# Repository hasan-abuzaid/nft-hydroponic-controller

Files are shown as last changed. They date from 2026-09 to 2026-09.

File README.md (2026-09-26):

# NFT Hydroponic Controller — Open-Hardware PCB

**Status: v1.1 boards fabricated and assembled by JLCPCB. Bring-up and on-site testing in progress.**

A 4-layer, ESP32-S3 based controller board that turns a manual NFT (Nutrient Film Technique) hydroponic system into a self-regulating one. It reads pH, EC and water level from the main reservoir, switches up to six 12 V pumps (nutrient A, nutrient B, pH adjust, circulation, …) and integrates natively with **Home Assistant** through **ESPHome**.

The goal: replace the breadboards, loose jumper wires and relay modules that most DIY hydroponic builds end up with, with one board you can order pre-assembled from JLCPCB, screw your sensors and pumps into, and flash.

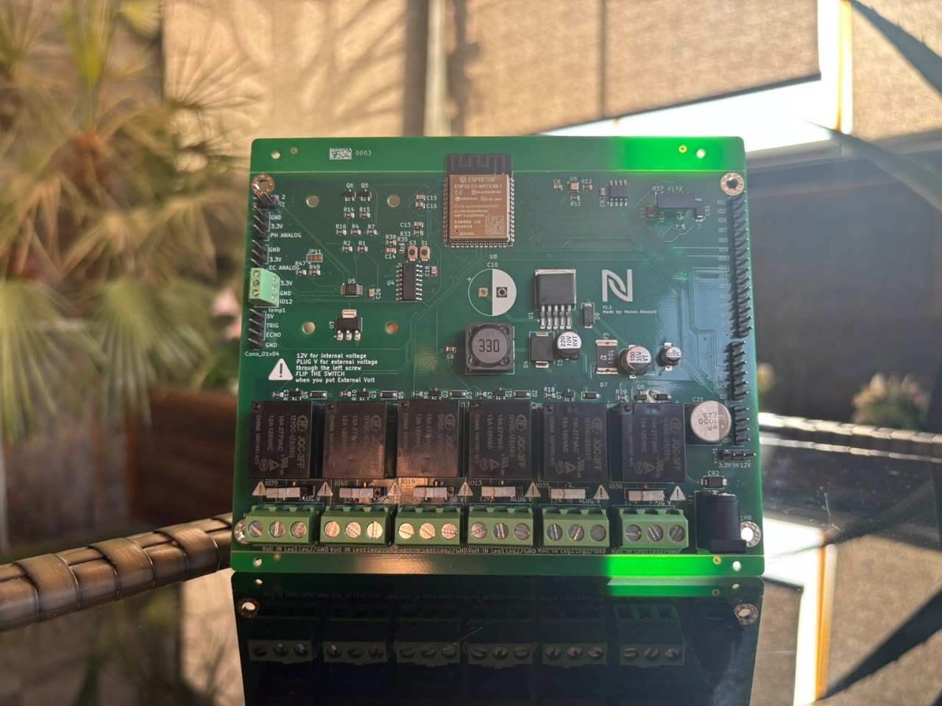
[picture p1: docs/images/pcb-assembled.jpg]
Assembled v1.1 board


---

## Why this exists

NFT systems work by running a thin film of nutrient solution under the plant roots. The hard part is not the plumbing, it is keeping the solution chemistry right: pH drifts, EC drops as plants feed, and the tank level falls. Doing that by hand every day is what makes most home systems fail.

This board closes that loop:

```
 pH / EC / level sensors ──► ESP32-S3 ──► Home Assistant (automations decide dose)
          ▲                                      │
          └──── main tank ◄── dosing pumps ◄── relays ◄─┘
```

The ESP reports readings, Home Assistant decides how much A/B nutrient or pH-down to dose based on calibrated set-points, and the board drives the pumps.

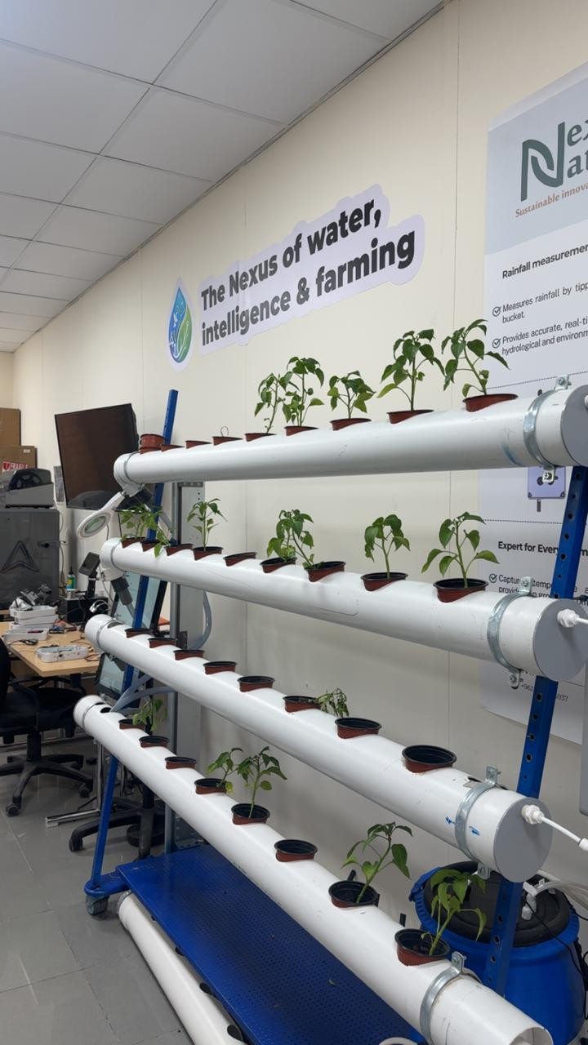
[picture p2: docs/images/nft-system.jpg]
The NFT system


---

## Features

| Block | Implementation |
|---|---|
| MCU | ESP32-S3-WROOM-1 (N16R8) — 16 MB flash, 8 MB PSRAM, Wi-Fi + BLE |
| USB | USB-C, CH340C USB-UART bridge with auto-reset/auto-boot (flash with no button presses), ESD protection on the data lines |
| Power input | 12 V DC barrel jack (DC-005, 2.0 mm) |
| Power conversion | LM2596S-5 buck (12 V → 5 V), AMS1117-3.3 LDO (5 V → 3.3 V) |
| Protection | SMAJ15A TVS on the 12 V rail, resettable polyfuse, Schottky OR-ing between USB and 12 V supply |
| Analog front-end | ADS1115 16-bit ADC for the pH and EC probe signals (far more stable than the ESP32's internal ADC) |
| Sensor inputs | pH and EC analog headers, water-temperature screw terminal, ultrasonic level header (5 V / TRIG / ECHO / GND), I²C header, GPIO breakout |
| Environment | On-board BME280 (air temperature, humidity, pressure) |
| Storage | MB85RC256V 32 KB I²C FRAM — stores calibration and state without flash wear |
| Outputs | 6× relay channels (JQC-3FF, SPDT) on 3-pin screw terminals (Volt IN / Leg 1 / Leg 2-GND), each with flyback diode and transistor driver |
| Load supply select | Per-channel switch: power the load from the board's internal 12 V, or from an external supply wired into that channel's Volt IN terminal |
| Buttons | BOOT and RESET |
| Power outputs | 3.3 V / 5 V / 12 V header for external modules |
| PCB | 4-layer, 1.6 mm, JLCPCB-ready (LCSC part numbers in the BOM) |

---

## Repository layout

```
.
├── nft-hydroponic-controller.kicad_pro   KiCad project (open this)
├── nft-hydroponic-controller.kicad_sch   Schematic
├── nft-hydroponic-controller.kicad_pcb   PCB layout
├── nft-hydroponic-controller.kicad_dru   Custom design rules
├── nft-hydroponic-controller.csv         Bill of materials with LCSC part numbers
├── nft-hydroponic-controller.xml         Netlist
├── DRC.rpt, ERC.rpt                      Design rule / electrical rule check reports
├── libs/lcsc/                Symbols, footprints and 3D models imported from LCSC
├── Custom_JLCPCB_Parts/      Custom parts library
├── compunents/               Additional vendor symbols/footprints
├── fp-lib-table, sym-lib-table   Project-relative library tables
├── firmware/esphome/         ESPHome config + secrets template
└── docs/images/              Photos and renders
```

All library paths are project-relative, so the project opens without missing symbols or footprints on a fresh machine.

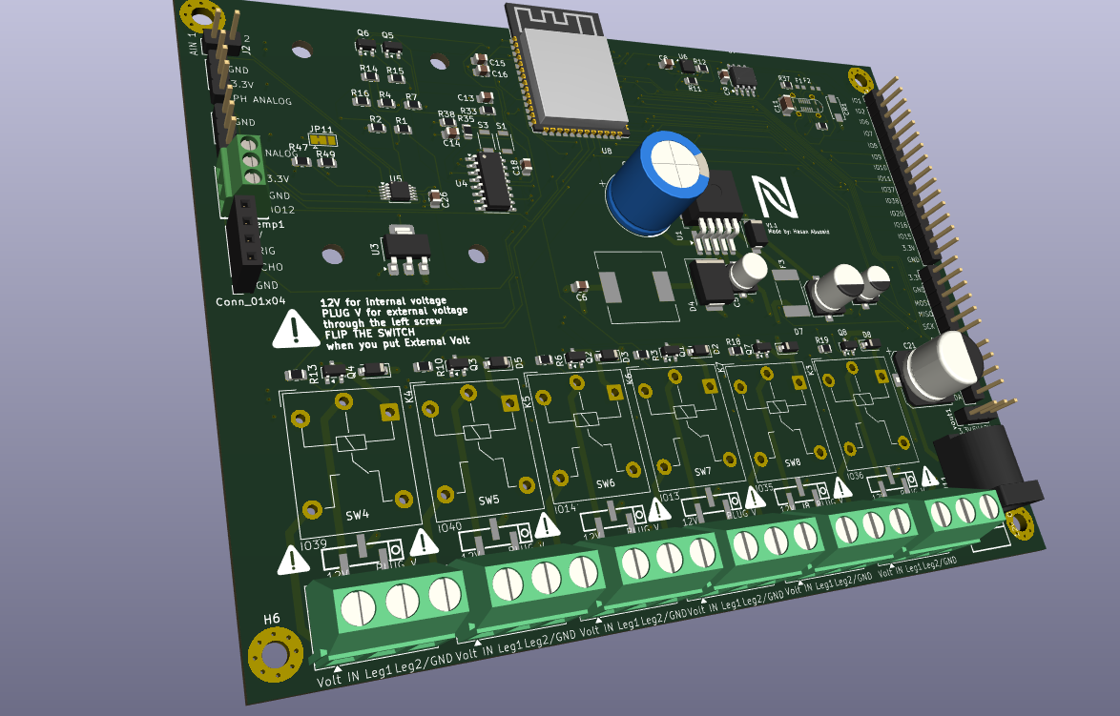
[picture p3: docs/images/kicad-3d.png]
3D render

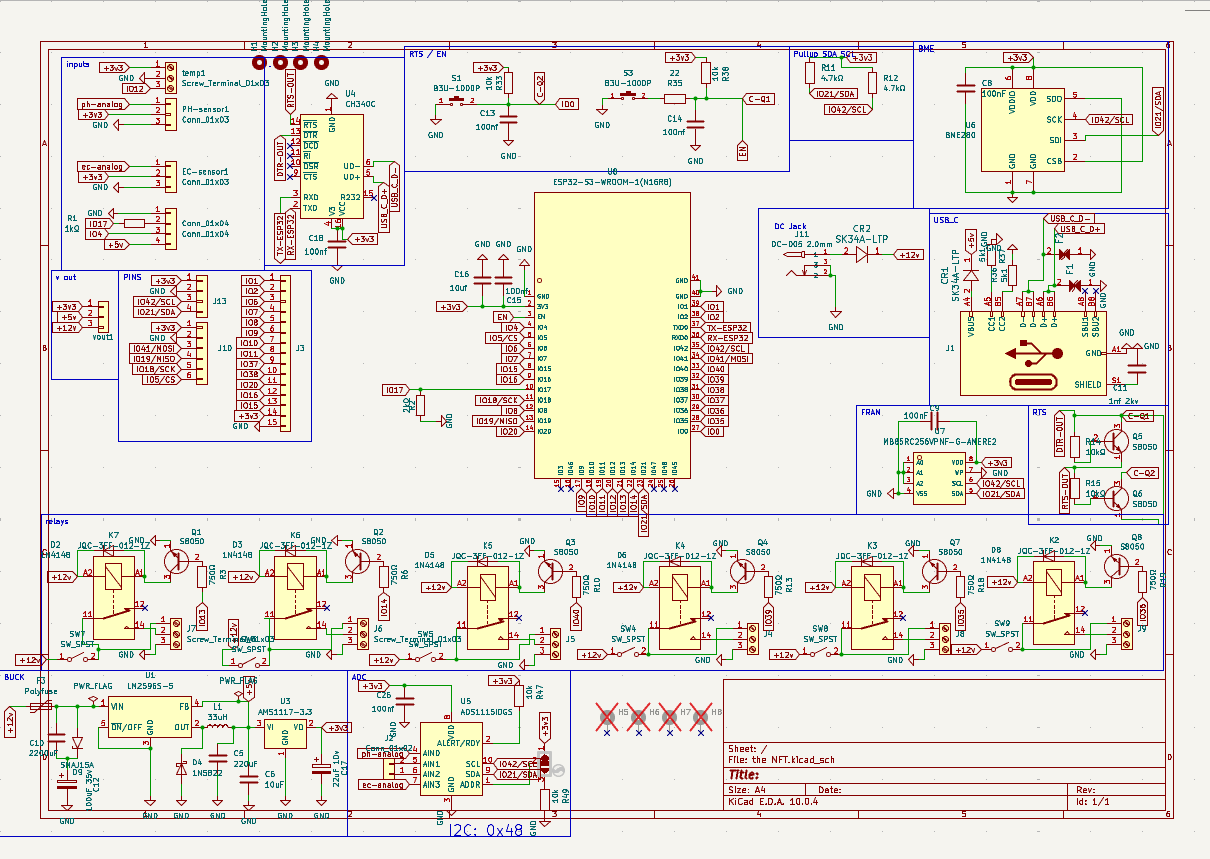
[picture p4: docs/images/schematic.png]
Schematic

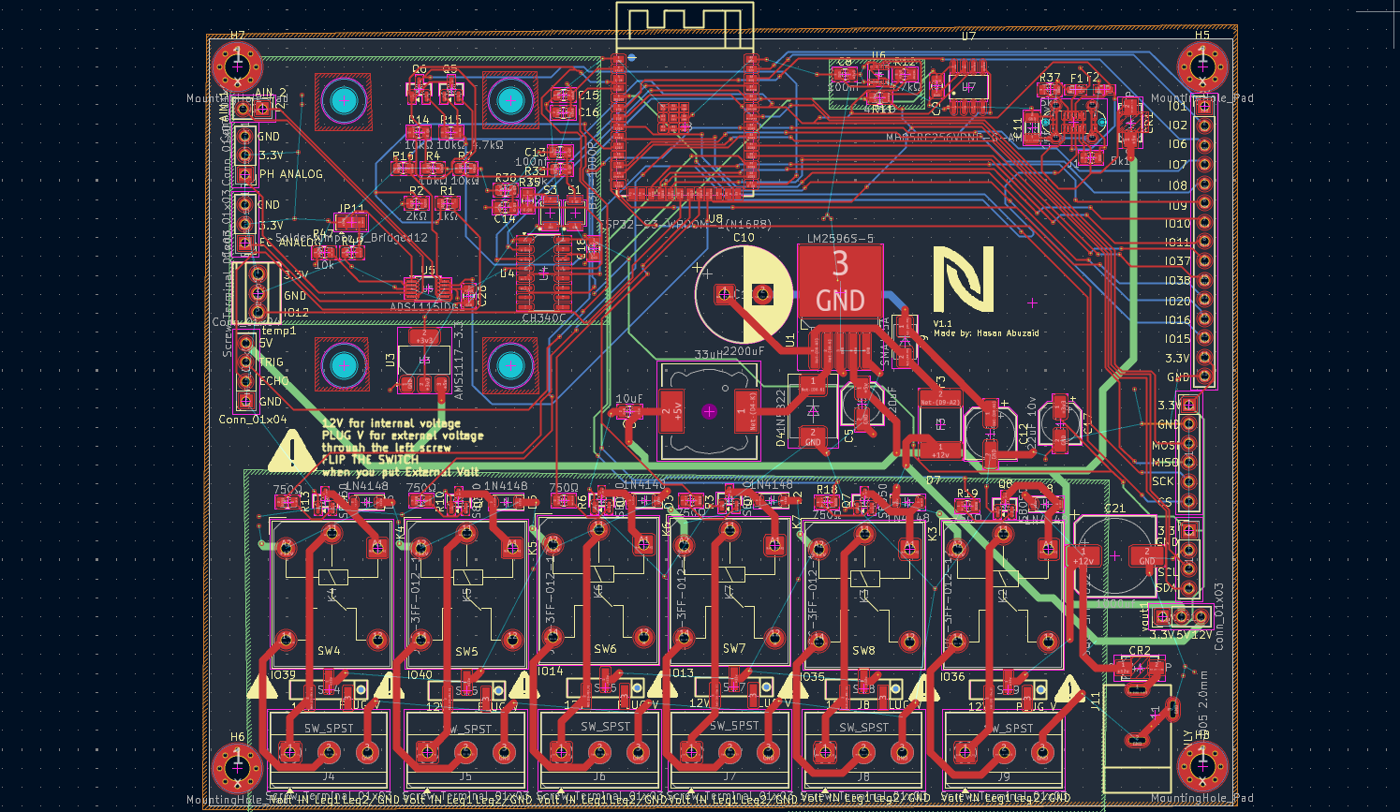
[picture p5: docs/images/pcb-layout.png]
PCB layout


---

## Requirements

- **KiCad 10** or newer (the files are saved in KiCad 10 format and will not open in older versions)
- Optional: the **Fabrication Toolkit** plugin (KiCad Plugin & Content Manager) to export JLCPCB-ready Gerbers, BOM and pick-and-place in one click — settings are included in `fabrication-toolkit-options.json`

---

## Ordering the board

1. Open `nft-hydroponic-controller.kicad_pro` in KiCad.
2. Open the PCB editor and run **Fabrication Toolkit** (or export Gerbers, drill files, BOM and CPL manually).
3. Upload the generated ZIP to JLCPCB. Select **4 layers**, 1.6 mm.
4. Enable **PCB Assembly** and upload the BOM and CPL. The LCSC part numbers are already assigned.
5. Through-hole parts (relays, screw terminals, barrel jack, large electrolytic) can be assembled by JLCPCB or hand-soldered.

Ready-made manufacturing files are also attached to each [Release](../../releases).

### Using the relay channels

Each channel's terminal block is **Volt IN / Leg 1 / Leg 2-GND**.

- **Internal 12 V (default):** leave the channel's switch in the internal position. The pump connects between Leg 1 and Leg 2-GND and runs from the board's 12 V input.
- **External voltage:** wire your supply into that channel's **Volt IN** terminal and flip the channel's switch to external. Use this for pumps or loads that need something other than 12 V.

---

## Pin mapping

| Function | ESP32-S3 GPIO |
|---|---|
| Relay 1 | `GPIO39` |
| Relay 2 | `GPIO40` |
| Relay 3 | `GPIO14` |
| Relay 4 | `GPIO13` |
| Relay 5 | `GPIO35` |
| Relay 6 | `GPIO36` |
| I²C SDA (ADS1115, BME280, FRAM) | `GPIO21` |
| I²C SCL | `GPIO42` |
| Water temperature | `GPIO12` |
| Ultrasonic level (trig / echo) | `GPIO4` / `GPIO17` (echo through a 1k/2k divider, 5 V-safe) |

ADS1115 (I²C address `0x48`): pH → `AIN0`, EC → `AIN3`.

---

## Firmware

The board runs **ESPHome** and reports to Home Assistant over **MQTT** (with MQTT discovery, so entities appear automatically). The config is in [`firmware/esphome/nutrient-controller.yaml`](firmware/esphome/nutrient-controller.yaml).

> This is the configuration used during development. Check the pin assignments against the [pin mapping](#pin-mapping) above before flashing it to the v1.1 board.

Setup:

1. Copy `firmware/esphome/secrets.yaml.example` to `secrets.yaml` and fill in your Wi-Fi, MQTT broker and passwords.
2. Plug the board into your computer via USB-C (no need to press BOOT, auto-reset is on board).
3. In Home Assistant → ESPHome Builder, create a device, paste the config, and choose **Install → Plug into this computer**.
4. After the first flash, updates happen over Wi-Fi.

---

## Calibration

pH and EC probes drift and vary between units, so set-points must be calibrated per probe:

- **pH:** two-point calibration with pH 4.0 and pH 7.0 buffer solutions.
- **EC:** calibrate with a known reference solution (e.g. 1413 µS/cm).
- **Dosing:** dose a small, measured volume, wait for the tank to mix, and record the change in pH/EC. This gives the "dose per unit change" used by the automations.

---

## Safety

- The relays are rated for mains voltage, but **this board is designed for 12 V DC loads only**. Do not switch mains through it unless you understand creepage/clearance requirements and have an enclosure rated for it.
- Water and electronics: mount the board above the reservoir, in an enclosure, with drip loops on every cable.
- Keep the pH-down acid and nutrient concentrates away from the electronics.

---

## Project status

| | |
|---|---|
| Revision | v1.1 |
| Boards | Fabricated and assembled (JLCPCB) |
| Tested | Not yet — bring-up results will be posted here |
| Known issues | Relays 5 and 6 use GPIO35/36. On the N16R8 module these pins are wired to the octal PSRAM. Leave PSRAM disabled in firmware and verify both channels during bring-up; fix planned for the next revision. |

---

## Contributing

Issues and pull requests are welcome, especially: tested pin mappings for other sensor probes, enclosure designs, and Home Assistant automation improvements. If you build one, open an issue with a photo.

---

## Credits

Designed by **Hasan Abuzaid** — Mechatronics Engineering, German Jordanian University.
Developed during an IoT/embedded internship at **Nexus Nature**.

## License

Hardware: [CERN-OHL-S-2.0](LICENSE). Firmware and configuration files: MIT.

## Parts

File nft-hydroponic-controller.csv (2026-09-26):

Reference | Qty | Value | DNP | Exclude from BOM | Exclude from Board | Footprint | Datasheet | LCSC# | LCSC | LCSC part
C5 | 1 | 220uF |  |  |  | Capacitor_SMD:C_Elec_5x5.4 |  |  |  | C3345
C6 | 1 | 10uF |  |  |  | Capacitor_SMD:C_0805_2012Metric
C8,C9 | 2 | 100nF |  |  |  | Capacitor_SMD:C_0805_2012Metric
C10 | 1 | 2200uF |  |  |  | Capacitor_THT:CP_Radial_D12.5mm_P5.00mm
C11 | 1 | 1nf 2kv |  |  |  | Capacitor_SMD:C_1206_3216Metric |  |  | C23631
C12 | 1 | 100uF 35v |  |  |  | Capacitor_SMD:CP_Elec_6.3x7.7
C13,C14,C15,C18,C26 | 5 | 100nf |  |  |  | Capacitor_SMD:C_0805_2012Metric |  |  | C476766
C16 | 1 | 10uf |  |  |  | Capacitor_SMD:C_0805_2012Metric |  |  | C95841
C17 | 1 | 22uF 10v |  |  |  | Capacitor_SMD:CP_Elec_5x5.4 |  |  |  | C602037
Conn_01x04 | 1 | Conn_01x04 |  |  |  | Connector_PinSocket_2.54mm:PinSocket_1x04_P2.54mm_Vertical |  |  |  | C53055674
CR1,CR2 | 2 | SK34A-LTP |  |  |  | SK34A-LTP:SMADO-214AC_MCC | SK34A-LTP |  | C85269
D2,D3,D5,D6,D7,D8 | 6 | 1N4148 |  |  |  | Diode_SMD:D_SOD-123 | https://assets.nexperia.com/documents/data-sheet/1N4148_1N4448.pdf
D4 | 1 | 1N5822 |  |  |  | Diode_SMD:D_SMC | http://www.vishay.com/docs/88526/1n5820.pdf
D9 | 1 | SMAJ15A |  |  |  | Diode_SMD:D_SMA | https://www.littelfuse.com/media?itemid=75e32973-b177-4ee3-a0ff-cedaf1abdb93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
EC-sensor1,PH-sensor1,vout1 | 3 | Conn_01x03 |  |  |  | Connector_PinHeader_2.54mm:PinHeader_1x03_P2.54mm_Vertical |  |  |  | C49257
F1,F2 | 2 | PGB1010603MRHF |  |  |  | PGB1010603:FUSE_PGB10106_LTF | PGB1010603MRHF |  | C2649884
F3 | 1 | Polyfuse |  |  |  | Fuse:Fuse_2920_7451Metric_Pad2.10x5.45mm_HandSolder |  |  |  | C70138
I2C1 | 1 | Conn_01x04 |  |  |  | Connector_PinHeader_2.54mm:PinHeader_1x04_P2.54mm_Vertical |  |  |  | C53055674
J1 | 1 | USB_C_Receptacle_USB2.0_16P |  |  |  | USB_TYPE_C_standing:USB_C_Standing | https://www.usb.org/sites/default/files/documents/usb_type-c.zip |  |  | C720628
J2 | 1 | Conn_01x02 |  |  |  | Connector_PinHeader_2.54mm:PinHeader_1x02_P2.54mm_Vertical |  |  |  | C53055672
J3 | 1 | Conn_01x15 |  |  |  | Connector_PinHeader_2.54mm:PinHeader_1x15_P2.54mm_Vertical |  |  |  | C2932704
J4,J5,J6,J7,J8,J9 | 6 | Screw_Terminal_01x03 |  |  |  | TerminalBlock_Phoenix:TerminalBlock_Phoenix_MKDS-1,5-3-5.08_1x03_P5.08mm_Horizontal |  |  |  | C395869
J10 | 1 | Conn_01x06 |  |  |  | Connector_PinHeader_2.54mm:PinHeader_1x06_P2.54mm_Vertical |  |  |  | C32713272
J11 | 1 | DC-005 2.0mm |  |  |  | lcsc_footprints:C84007_DC-IN-TH_DC-005C-20A | https://www.lcsc.com/datasheet/lcsc_datasheet_2108131530_Korean-Hroparts-Elec-DC-005C-20A_C84007.pdf |  | C84007
K2,K3,K4,K5,K6,K7 | 6 | JQC-3FF-012-1Z |  |  |  | Relay_THT:Relay_SPDT_Hongfa_JQC-3FF_0XX-1Z | https://www.digikey.com/htmldatasheets/production/2071105/0/0/1/JQC-3FF.pdf |  |  | C2976875
L1 | 1 | 33uH |  |  |  | Inductor_SMD:L_12x12mm_H6mm
Q1,Q2,Q3,Q4,Q5,Q6,Q7,Q8 | 8 | S8050 |  |  |  | Package_TO_SOT_SMD:SOT-23 | http://www.unisonic.com.tw/datasheet/S8050.pdf
R1,R2 | 2 | 1kΩ |  |  |  | Resistor_SMD:R_0805_2012Metric
R3,R6,R10,R13,R18,R19 | 6 | 750Ω |  |  |  | Resistor_SMD:R_0805_2012Metric
R11,R12 | 2 | 4.7kΩ |  |  |  | Resistor_SMD:R_0805_2012Metric
R14,R15 | 2 | 10kΩ |  |  |  | Resistor_SMD:R_0805_2012Metric
R33,R38,R47,R49 | 4 | 10k |  |  |  | Resistor_SMD:R_0805_2012Metric |  |  | C17414
R35 | 1 | 22 |  |  |  | Resistor_SMD:R_0805_2012Metric |  |  | C17561
R36,R37 | 2 | 5k1 |  |  |  | Resistor_SMD:R_0805_2012Metric |  |  | C2930296
S1,S3 | 2 | B3U-1000P |  |  |  | B3U-1000P:SW_B3U-1000P |  |  | C231329
SW4,SW5,SW6,SW7,SW8,SW9 | 6 | SW_SPST |  |  |  | lcsc_footprints:C515802_SW-SMD_NSI-10S |  |  |  | C515802
temp1 | 1 | Screw_Terminal_01x03 |  |  |  | lcsc_footprints:C474921_CONN-TH_3P-P2_54_KF128-2_54-3P |  |  |  | C395869
U1 | 1 | LM2596S-5 |  |  |  | Package_TO_SOT_SMD:TO-263-5_TabPin3 | http://www.ti.com/lit/ds/symlink/lm2596.pdf
U3 | 1 | AMS1117-3.3 |  |  |  | Package_TO_SOT_SMD:SOT-223-3_TabPin2 | http://www.advanced-monolithic.com/pdf/ds1117.pdf
U4 | 1 | CH340C |  |  |  | Package_SO:SOIC-16_3.9x9.9mm_P1.27mm | https://datasheet.lcsc.com/szlcsc/Jiangsu-Qin-Heng-CH340C_C84681.pdf
U5 | 1 | ADS1115IDGS |  |  |  | Package_SO:TSSOP-10_3x3mm_P0.5mm | http://www.ti.com/lit/ds/symlink/ads1113.pdf
U6 | 1 | BME280 |  |  |  | Package_LGA:Bosch_LGA-8_2.5x2.5mm_P0.65mm_ClockwisePinNumbering | https://www.bosch-sensortec.com/media/boschsensortec/downloads/datasheets/bst-bme280-ds002.pdf
U7 | 1 | MB85RC256VPNF-G-AMERE2 |  |  |  | lcsc_footprints:C45273903_SOP-8_L4_9-W3_9-P1_27-LS6_0-BL | None |  | C45273903
U8 | 1 | ESP32-S3-WROOM-1(N16R8) |  |  |  | lcsc_footprints:C2913202_WIRELM-SMD_ESP32-S3-WROOM-1 | https://www.lcsc.com/datasheet/lcsc_datasheet_2411121101_Espressif-Systems-ESP32-S3-WROOM-1-N16R8_C2913202.pdf |  | C2913202

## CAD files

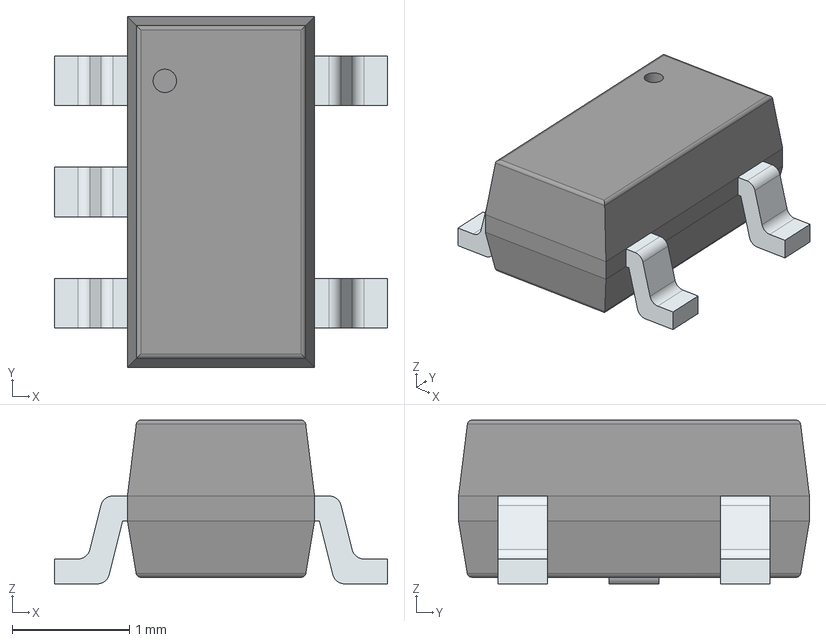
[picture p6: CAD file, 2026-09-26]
compunents/AP2171WG-7/AP2171WG-7.stp
2.85 x 3.00 x 1.40 mm
PinsArrayL
PinsArrayR

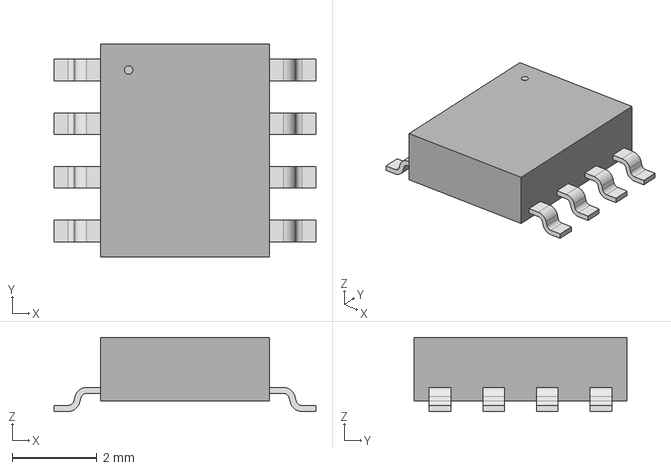
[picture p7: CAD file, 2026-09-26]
compunents/AT24C32/8S1_MCH.step
6.20 x 5.05 x 1.75 mm

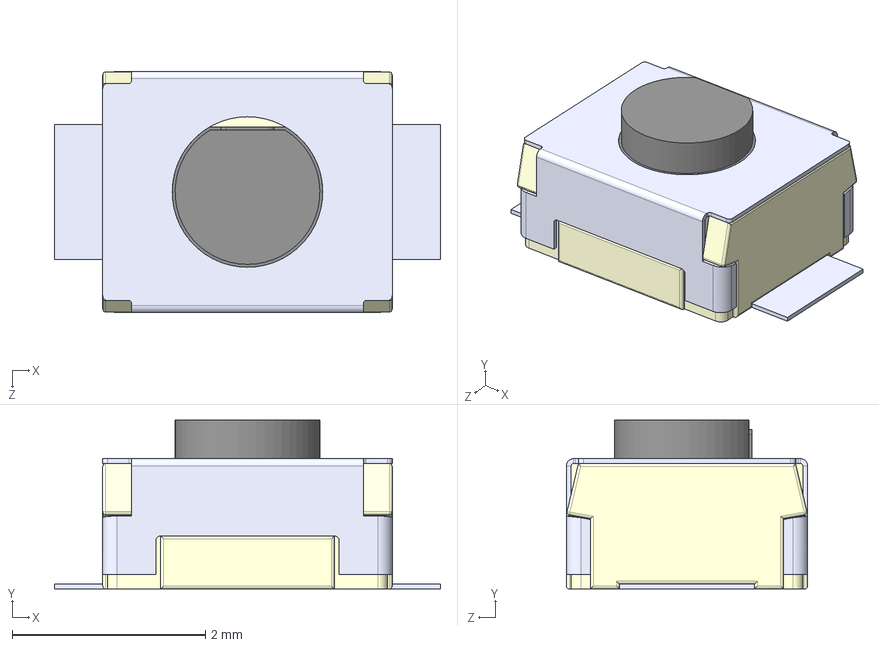
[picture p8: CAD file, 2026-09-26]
compunents/B3U-1000P/B3U-1000P.step
4.00 x 1.75 x 2.50 mm

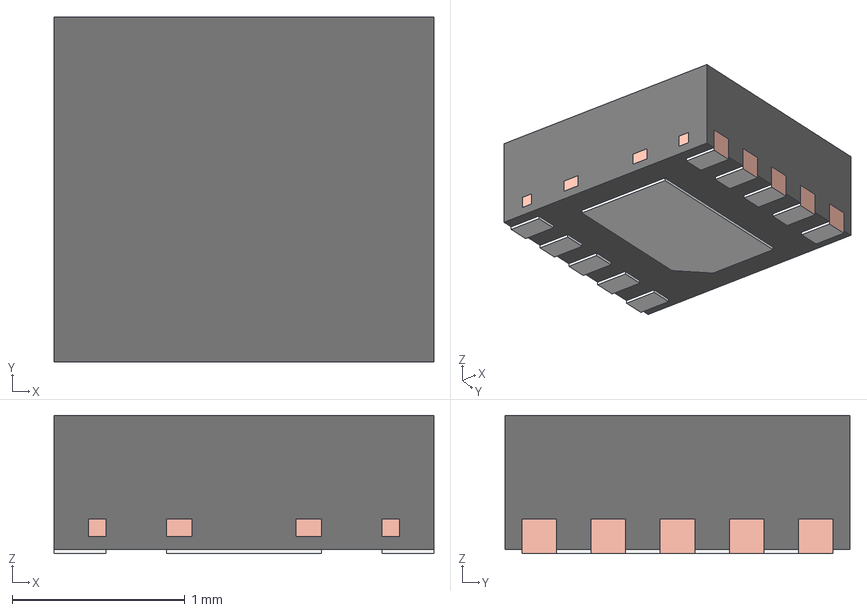
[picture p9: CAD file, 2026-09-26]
compunents/BQ25185/DLH0010A.stp
2.20 x 2.00 x 0.8 mm
BODY-SON
FRAME-DLH0010A
PIN1-ID

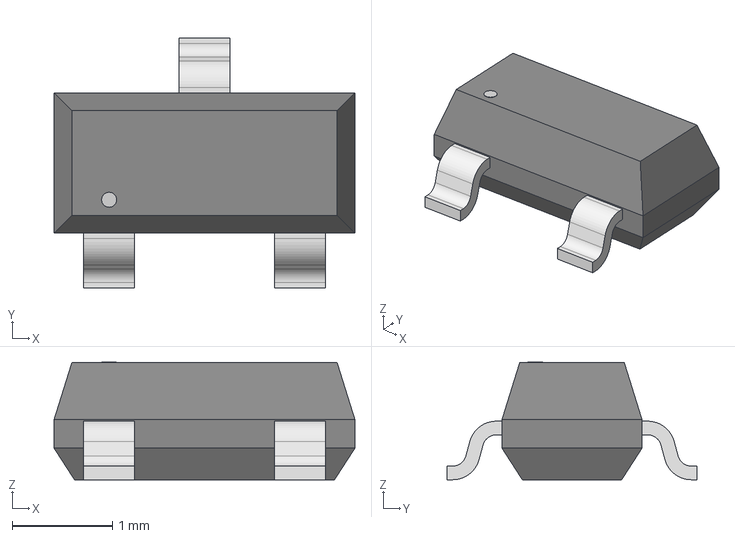
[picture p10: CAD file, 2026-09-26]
compunents/CDSOT23-SM712/SOT_SM712.step
3.00 x 2.49 x 1.17 mm

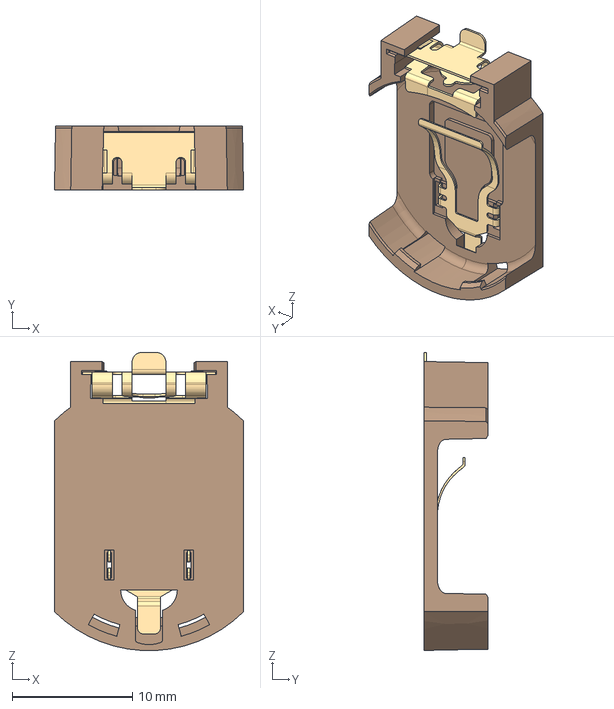
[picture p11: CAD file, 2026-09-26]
compunents/CR2032/S8421-45R.step
15.7 x 5.30 x 24.7 mm

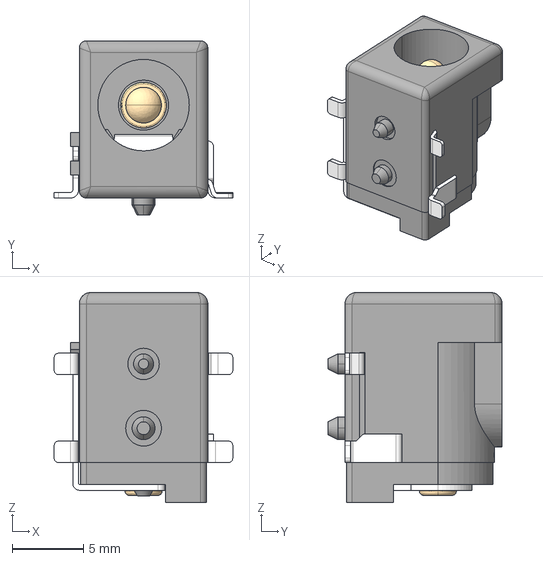
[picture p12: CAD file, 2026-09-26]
compunents/DC050-2.5-T/DC050-2.5-T.step
12.5 x 12.2 x 14.7 mm

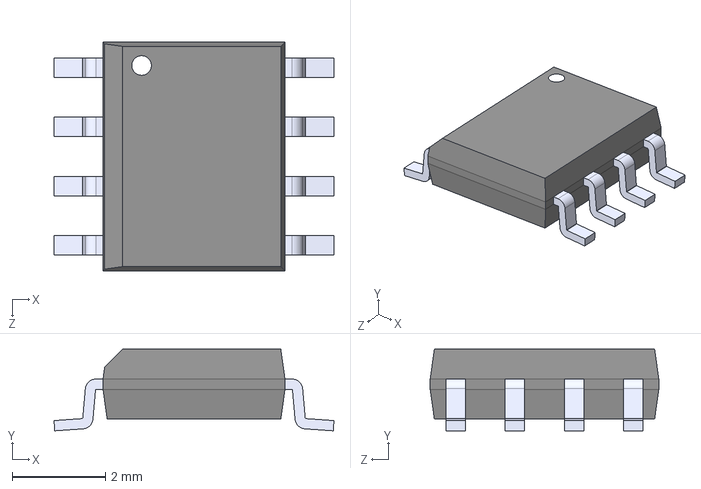
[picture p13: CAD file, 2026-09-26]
compunents/DS3231m/DS3231MZ_TRL.step
6.00 x 1.75 x 4.90 mm

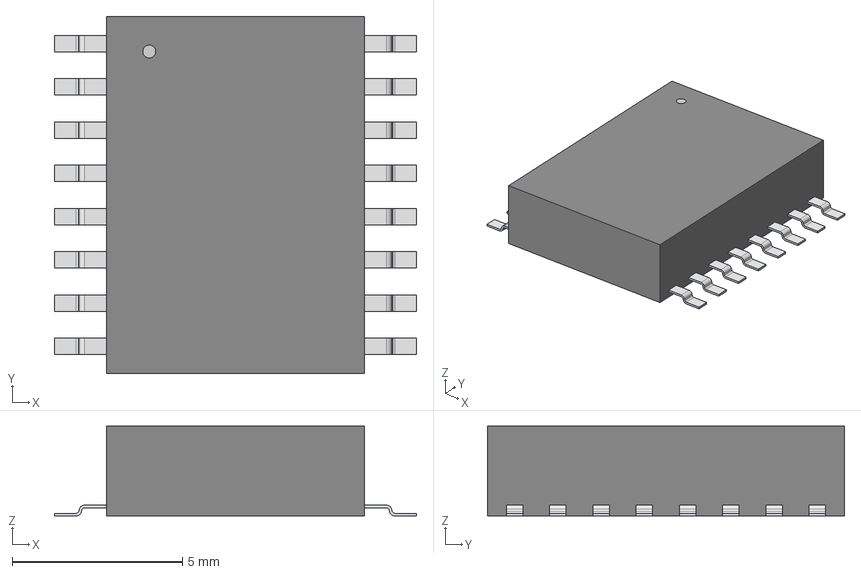
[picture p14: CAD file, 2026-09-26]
compunents/DS3231SN#T&R/DS3231S.step
10.6 x 10.5 x 2.64 mm

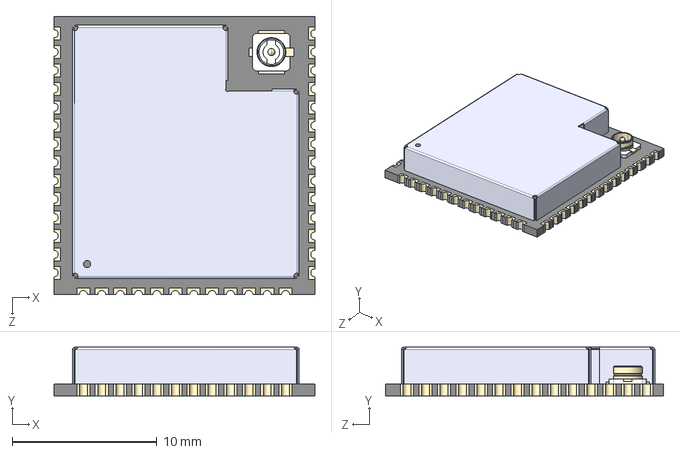
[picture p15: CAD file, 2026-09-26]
compunents/ESP32-S3-WROOM-1U-N16R8/ESP32-S3-WROOM-1U-N16R8.step
18.0 x 3.35 x 19.2 mm

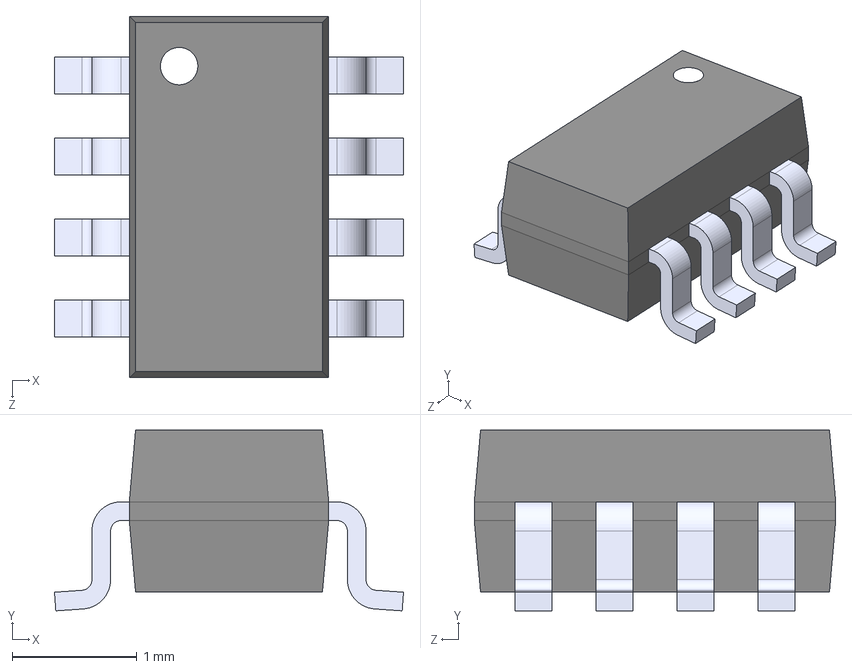
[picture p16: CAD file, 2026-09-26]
compunents/INA219AIDCNR/INA219AIDCNR.step
2.80 x 1.45 x 2.90 mm

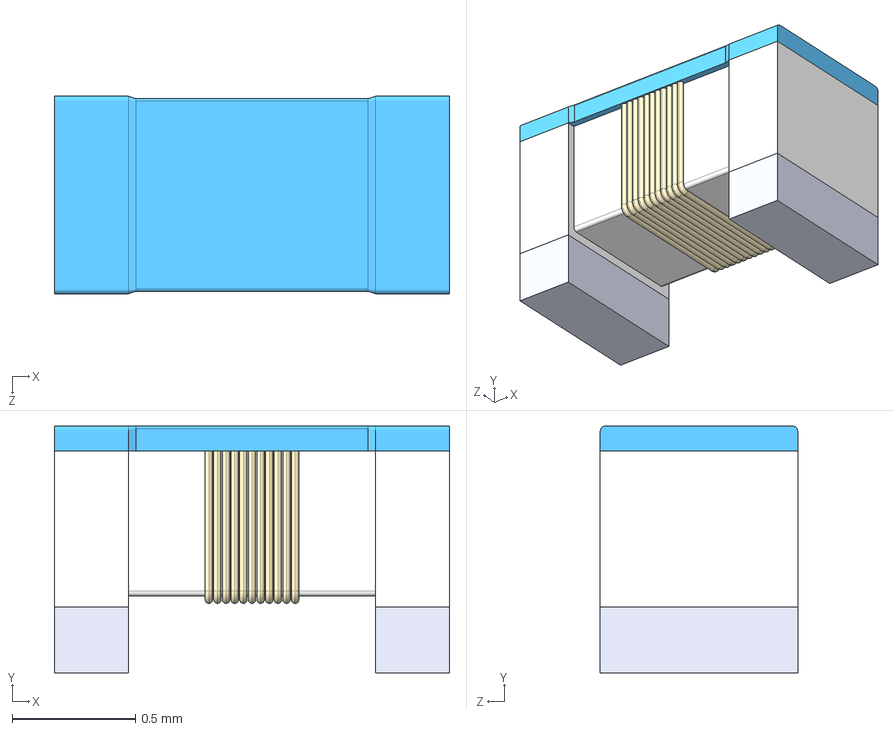
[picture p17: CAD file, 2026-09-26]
compunents/LQW18AN56NG00D/LQW18AN56NG00D.step
1.60 x 1.00 x 0.8 mm

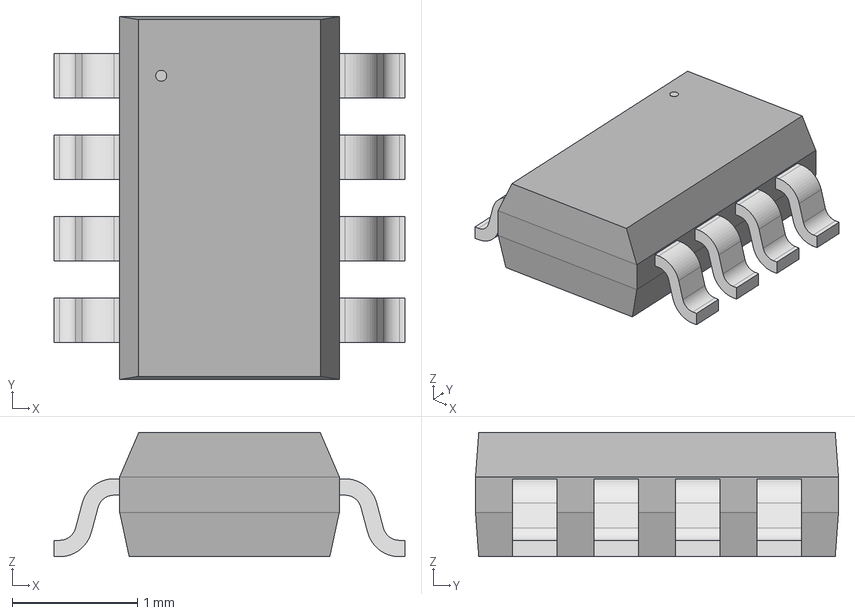
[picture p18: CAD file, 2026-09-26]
compunents/LTC2451/LTC2451CTS8TRMPBF_ADI.step
2.80 x 2.90 x 0.993 mm

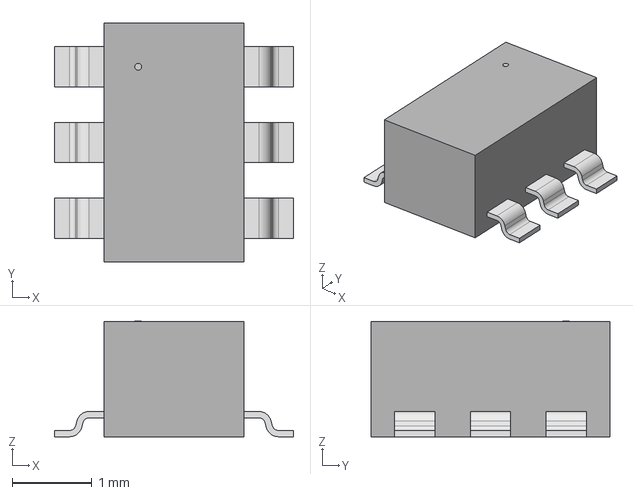
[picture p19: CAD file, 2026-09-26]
compunents/MAX44284/21-0058I_MXM.step
3.00 x 3.00 x 1.45 mm

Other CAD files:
compunents/PGB1010603/FUSE_PGB10106_LTF.step
compunents/PJ-066A/PJ-066A.STEP
compunents/PTS526/SON4_PTS526SM15SMTR2LFS_CNK.step
compunents/PTS636/SW_PTS636_CNK.step
compunents/Amphenol ICC 12401832E402A/12401832E402A.step
compunents/BQ24074RGTR/BQ24074RGTR.step
compunents/MOLEX 1040310811 - SD card/104031-0811.step
compunents/MOLEX 1042240820 - nanosim/1042240820.stp
compunents/SIM7600E-H/SIM7600E-H.step
compunents/SMA/132134-11.stp
compunents/SMA/RFPC-SMA27-F.step
compunents/SMF05CT1G/SMF05CT1G.step
compunents/THVD1400DRLR/DRL0008A.stp
compunents/TLV62130A/TLV62130A.stp
compunents/TPS22958DGNR/DGN0008G.stp
compunents/TPS61022RWUR/TPS61022RWUR.step
compunents/TPS62840DLC/TPS62840DLCR.step
compunents/TPS630701RNMR/TPS630701RNMR.stp
compunents/TXB0108RGYR/TXB0108RGYRG4.step
compunents/U.FL-R-SMT-1/U.FL-R-SMT-1_10_.step
compunents/XAL6030-102MEC/XAL6030-102MEC.stp
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

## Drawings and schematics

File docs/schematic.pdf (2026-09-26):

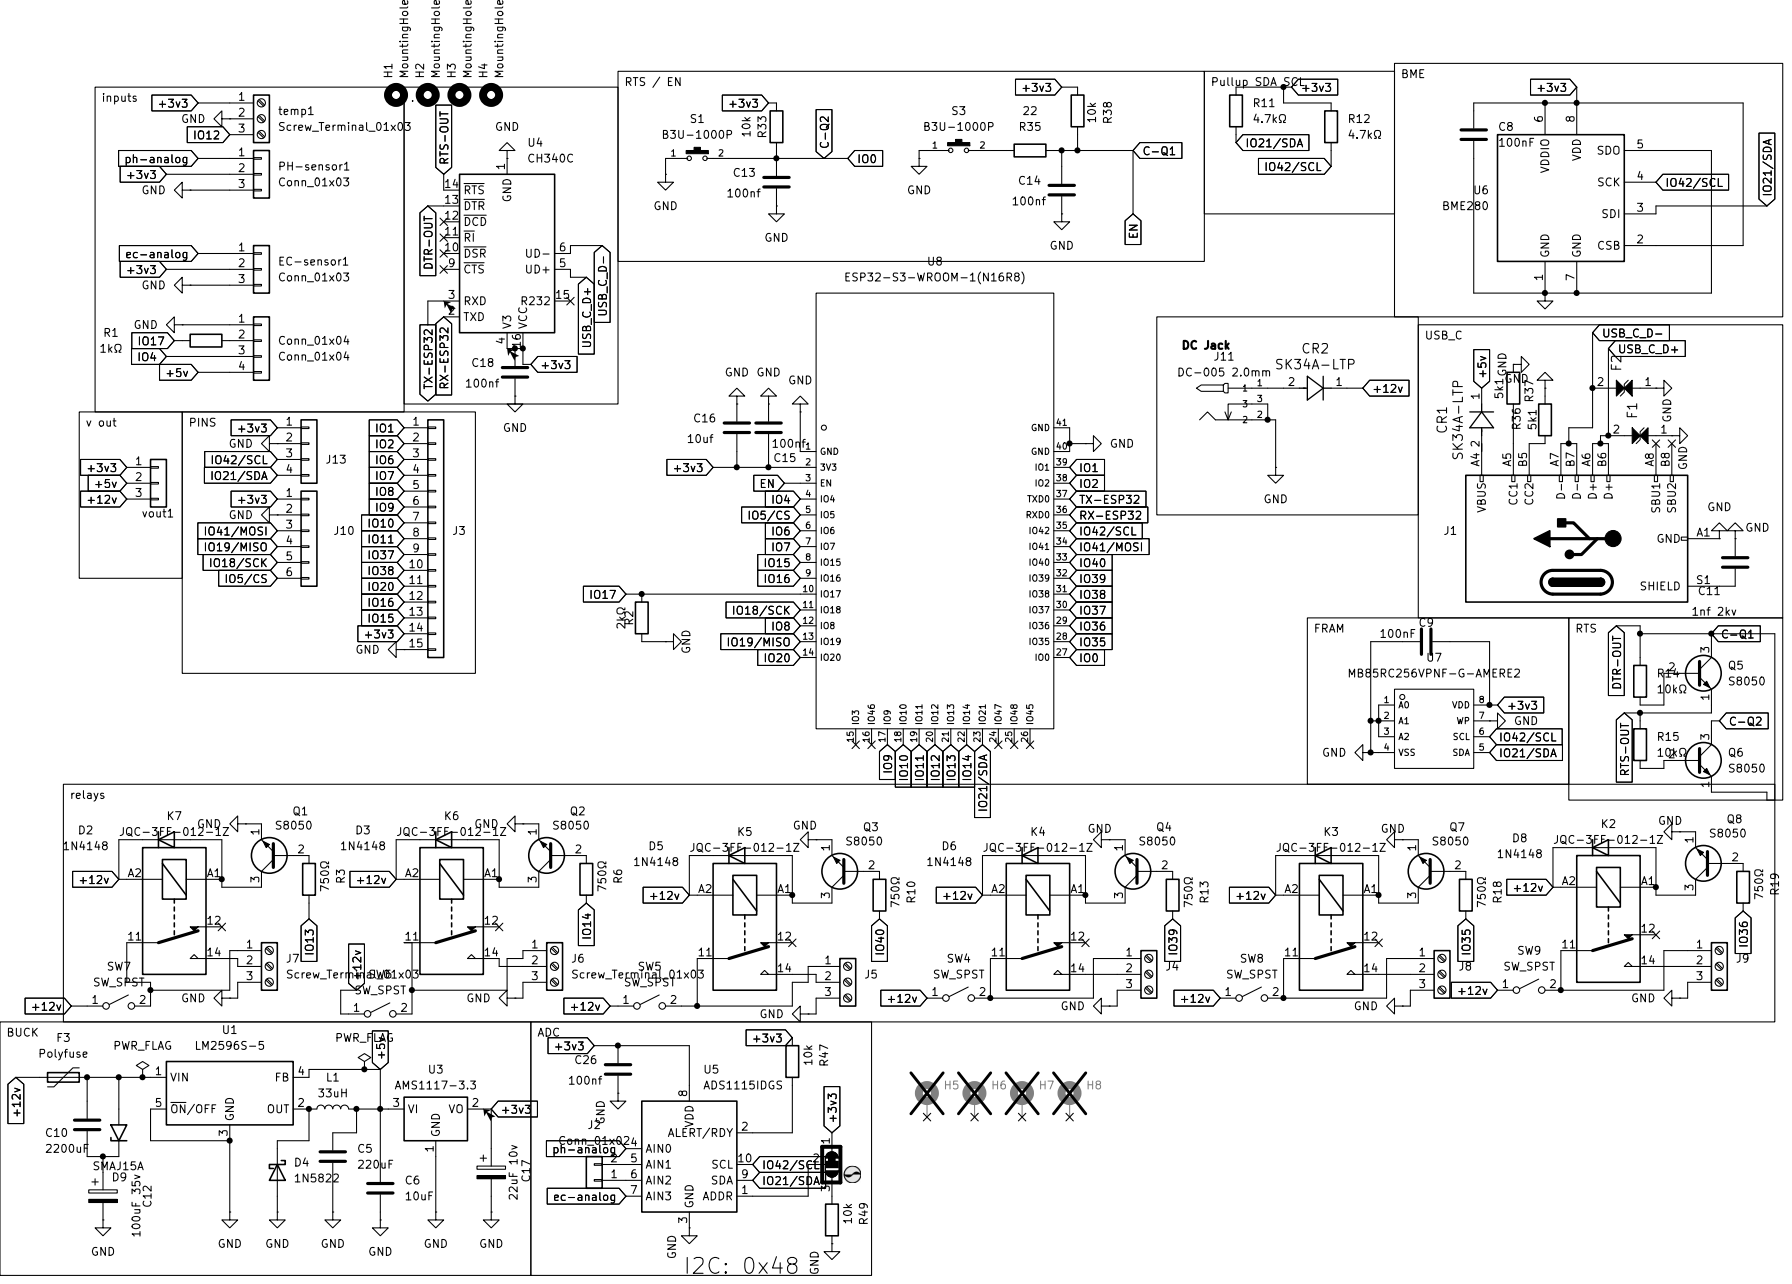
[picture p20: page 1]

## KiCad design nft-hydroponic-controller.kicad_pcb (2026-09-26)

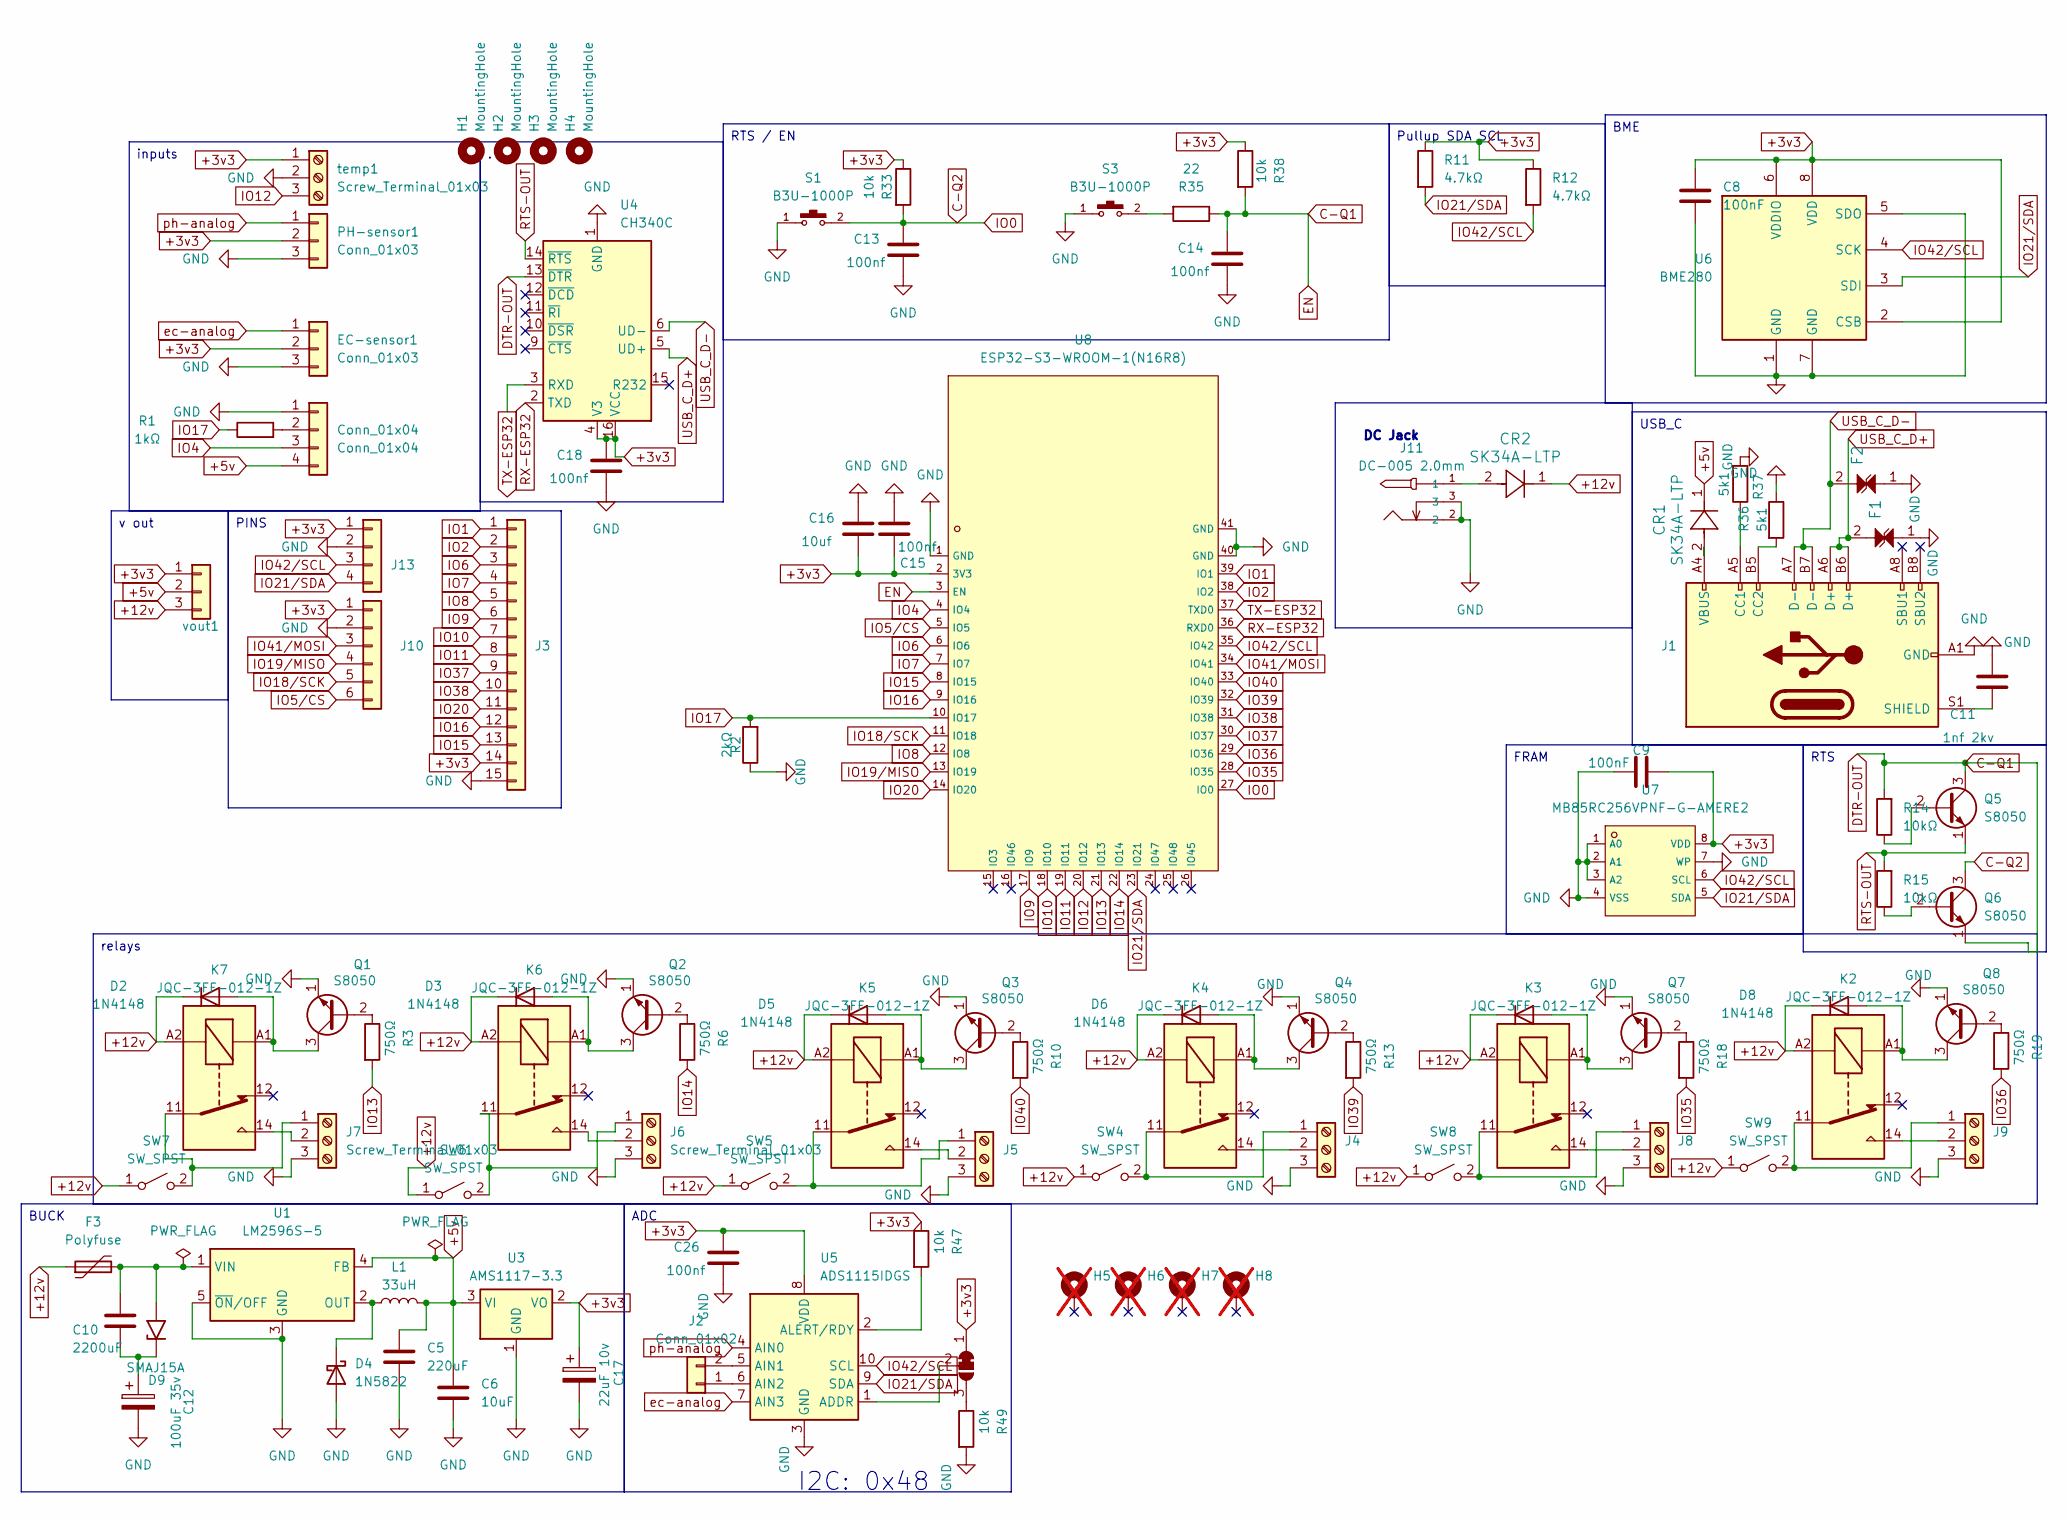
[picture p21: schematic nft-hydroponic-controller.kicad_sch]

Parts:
C5: 220uF; C_Elec_5x5.4; LCSC part C3345
C6: 10uF; C_0805_2012Metric
C8, C9: 100nF; C_0805_2012Metric
C10: 2200uF; CP_Radial_D12.5mm_P5.00mm
C11: 1nf 2kv; C_1206_3216Metric; LCSC C23631
C12: 100uF 35v; CP_Elec_6.3x7.7
C13, C14, C15, C18, C26: 100nf; C_0805_2012Metric; LCSC C476766
C16: 10uf; C_0805_2012Metric; LCSC C95841
C17: 22uF 10v; CP_Elec_5x5.4; LCSC part C602037
CR1, CR2: SK34A-LTP; SMADO-214AC_MCC; LCSC C85269
Conn_01x04: Conn_01x04; PinSocket_1x04_P2.54mm_Vertical; LCSC part C53055674
D2, D3, D5, D6, D7, D8: 1N4148; D_SOD-123
D4: 1N5822; D_SMC
D9: SMAJ15A; D_SMA
EC-sensor1: Conn_01x03; PinHeader_1x03_P2.54mm_Vertical; LCSC part C49257
F1, F2: PGB1010603MRHF; FUSE_PGB10106_LTF; LCSC C2649884
F3: Polyfuse; Fuse_2920_7451Metric_Pad2.10x5.45mm_HandSolder; LCSC part C70138
H1, H2, H3, H4: MountingHole; MountingHole_3.2mm_M3_ISO7380
H5, H6, H7, H8: MountingHole_Pad; MountingHole_3.2mm_M3_Pad_Via; not fitted
J1: USB_C_Receptacle_USB2.0_16P; USB_C_Standing; LCSC part C720628
J2: Conn_01x02; PinHeader_1x02_P2.54mm_Vertical; LCSC part C53055672
J3: Conn_01x15; PinHeader_1x15_P2.54mm_Vertical; LCSC part C2932704
J4, J5, J6, J7, J8, J9: Screw_Terminal_01x03; TerminalBlock_Phoenix_MKDS-1,5-3-5.08_1x03_P5.08mm_Horizont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; LCSC part C395869
J10: Conn_01x06; PinHeader_1x06_P2.54mm_Vertical; LCSC part C32713272
J11: DC-005 2.0mm; C84007_DC-IN-TH_DC-005C-20A; LCSC C84007
J13: Conn_01x04; PinHeader_1x04_P2.54mm_Vertical; LCSC part C53055674
JP11: SolderJumper_3_Bridged12; SolderJumper-3_P1.3mm_Bridged12_Pad1.0x1.5mm
K2, K3, K4, K5, K6, K7: JQC-3FF-012-1Z; Relay_SPDT_Hongfa_JQC-3FF_0XX-1Z; LCSC part C2976875
L1: 33uH; L_12x12mm_H6mm
PH-sensor1: Conn_01x03; PinHeader_1x03_P2.54mm_Vertical; LCSC part C49257
Q1, Q2, Q3, Q4, Q5, Q6, Q7, Q8: S8050; SOT-23
R1: 1kΩ; R_0805_2012Metric
R2: 2kΩ; R_0805_2012Metric
R3, R6, R10, R13, R18, R19: 750Ω; R_0805_2012Metric
R11, R12: 4.7kΩ; R_0805_2012Metric
R14, R15: 10kΩ; R_0805_2012Metric
R33, R38, R47, R49: 10k; R_0805_2012Metric; LCSC C17414
R35: 22; R_0805_2012Metric; LCSC C17561
R36, R37: 5k1; R_0805_2012Metric; LCSC C2930296
S1, S3: B3U-1000P; SW_B3U-1000P; LCSC C231329
SW4, SW5, SW6, SW7, SW8, SW9: SW_SPST; C515802_SW-SMD_NSI-10S; LCSC part C515802
U1: LM2596S-5; TO-263-5_TabPin3
U3: AMS1117-3.3; SOT-223-3_TabPin2
U4: CH340C; SOIC-16_3.9x9.9mm_P1.27mm
U5: ADS1115IDGS; TSSOP-10_3x3mm_P0.5mm
U6: BME280; Bosch_LGA-8_2.5x2.5mm_P0.65mm_ClockwisePinNumbering
U7: MB85RC256VPNF-G-AMERE2; C45273903_SOP-8_L4_9-W3_9-P1_27-LS6_0-BL; LCSC C45273903
U8: ESP32-S3-WROOM-1(N16R8); C2913202_WIRELM-SMD_ESP32-S3-WROOM-1; LCSC C2913202
temp1: Screw_Terminal_01x03; C474921_CONN-TH_3P-P2_54_KF128-2_54-3P; LCSC part C395869
vout1: Conn_01x03; PinHeader_1x03_P2.54mm_Vertical; LCSC part C49257

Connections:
+3v3: C8.2, C9.1, C15.2, C16.1, C17.1, C18.2, C26.2, EC-sensor1.2, J3.14, J10.1, J13.1, JP11.1 (A), PH-sensor1.2, R11.1, R12.1, R33.1, R38.1, R47.1, U3.2 (VO), U4.4 (V3), U4.16 (VCC), U5.8 (VDD), U6.2 (CSB), U6.6 (VDDIO), U6.8 (VDD), U7.8 (VDD), U8.2 (3V3), temp1.1, vout1.1; also elsewhere on the board
+5v: C5.1, C6.1, CR1.1, Conn_01x04.4, L1.2, U1.4 (FB), U3.3 (VI), vout1.2
+12v: CR2.1, D2.1 (K), D3.1 (K), D5.1 (K), D6.1 (K), D7.1 (K), D8.1 (K), F3.1, K2.A2, K3.A2, K4.A2, K5.A2, K6.A2, K7.A2, SW4.1 (A), SW5.1 (A), SW6.1 (A), SW7.1 (A), SW8.1 (A), SW9.1 (A), vout1.3; also elsewhere on the board
C-Q1: C14.2, Q5.3 (C), Q6.1 (E), R14.2, R35.1, R38.2, U4.13 (~DTR), U8.3 (EN); also elsewhere on the board
C-Q2: C13.2, Q6.3 (C), R33.2, S1.2, U8.27 (IO0); also elsewhere on the board
GND: C5.2, C6.2, C8.1, C9.2, C11.2, C12.2, C13.1, C14.1, C15.1, C16.2, C17.2, C18.1, C26.1, Conn_01x04.1, D4.2 (A), EC-sensor1.3, F1.1, F2.1, J1.A1 (GND), J1.A12 (GND), J1.B1 (GND), J1.B12 (GND), J3.15, J4.3, J5.3, J6.3, J7.3, J8.3, J9.3, J10.2, J11.2, J11.3, J13.2, PH-sensor1.3, Q1.1 (E), Q2.1 (E), Q3.1 (E), Q4.1 (E), Q7.1 (E), Q8.1 (E), R2.1, R36.1, R37.2, R49.2, S1.1, S3.1, U1.3 (GND), U1.5 (~ON/OFF), U3.1 (GND), U4.1 (GND), U5.3 (GND), U6.1 (GND), U6.5 (SDO), U6.7 (GND), U7.1 (A0), U7.2 (A1), U7.3 (A2), U7.4 (VSS), U7.7 (WP), U8.1 (GND), U8.40 (GND), U8.41 (GND), temp1.2; also elsewhere on the board
IO1: J3.1, U8.39 (IO1)
IO2: J3.2, U8.38 (IO2)
IO4: Conn_01x04.3, U8.4 (IO4)
IO5/CS: J10.6, U8.5 (IO5)
IO6: J3.3, U8.6 (IO6)
IO7: J3.4, U8.7 (IO7)
IO8: J3.5, U8.12 (IO8)
IO9: J3.6, U8.17 (IO9)
IO10: J3.7, U8.18 (IO10)
IO11: J3.8, U8.19 (IO11)
IO12: U8.20 (IO12), temp1.3
IO13: R3.2, U8.21 (IO13)
IO14: R6.2, U8.22 (IO14)
IO15: J3.13, U8.8 (IO15)
IO16: J3.12, U8.9 (IO16)
IO17: R1.1, R2.2, U8.10 (IO17)
IO18/SCK: J10.5, U8.11 (IO18)
IO19/MISO: J10.4, U8.13 (IO19)
IO20: J3.11, U8.14 (IO20)
IO21/SDA: J13.4, R11.2, U5.9 (SDA), U6.3 (SDI), U7.5 (SDA), U8.23 (IO21)
IO35: R18.2, U8.28 (IO35)
IO36: R19.2, U8.29 (IO36)
IO37: J3.9, U8.30 (IO37)
IO38: J3.10, U8.31 (IO38)
IO39: R13.2, U8.32 (IO39)
IO40: R10.2, U8.33 (IO40)
IO41/MOSI: J10.3, U8.34 (IO41)
IO42/SCL: J13.3, R12.2, U5.10 (SCL), U6.4 (SCK), U7.6 (SCL), U8.35 (IO42); also elsewhere on the board
unnamed: CR1.2, J1.A4 (VBUS), J1.A9 (VBUS), J1.B4 (VBUS), J1.B9 (VBUS)
unnamed: CR2.2, J11.1
unnamed: Conn_01x04.2, R1.2
unnamed: D2.2 (A), K7.A1, Q1.3 (C)
unnamed: D3.2 (A), K6.A1, Q2.3 (C)
unnamed: D4.1 (K), L1.1, U1.2 (OUT)
unnamed: D5.2 (A), K5.A1, Q3.3 (C)
unnamed: D6.2 (A), K4.A1, Q4.3 (C)
unnamed: D7.2 (A), K3.A1, Q7.3 (C)
unnamed: D8.2 (A), K2.A1, Q8.3 (C)
unnamed: C10.2, C12.1, D9.1 (A1)
unnamed: C10.1, D9.2 (A2), F3.2, U1.1 (VIN)
unnamed: J1.A5 (CC1), R37.1
unnamed: J1.B5 (CC2), R36.2
unnamed: C11.1, J1.S1 (SHIELD)
unnamed: J2.1, U5.6 (AIN2)
unnamed: J2.2, U5.5 (AIN1)
unnamed: J4.1, K4.11, SW4.2 (B)
unnamed: J4.2, K4.14
unnamed: J5.1, K5.11, SW5.2 (B)
unnamed: J5.2, K5.14
unnamed: J6.1, K6.11, SW6.2 (B)
unnamed: J6.2, K6.14
unnamed: J7.1, K7.11, SW7.2 (B)
unnamed: J7.2, K7.14
unnamed: J8.1, K3.11, SW8.2 (B)
unnamed: J8.2, K3.14
unnamed: J9.1, K2.11, SW9.2 (B)
unnamed: J9.2, K2.14
unnamed: JP11.3 (B), R49.1
unnamed: JP11.2 (C), U5.1 (ADDR)
unnamed: Q1.2 (B), R3.1
unnamed: Q2.2 (B), R6.1
unnamed: Q3.2 (B), R10.1
unnamed: Q4.2 (B), R13.1
unnamed: Q5.2 (B), R14.1
unnamed: Q6.2 (B), R15.1
unnamed: Q7.2 (B), R18.1
unnamed: Q8.2 (B), R19.1
unnamed: R35.2, S3.2
unnamed: R47.2, U5.2 (ALERT/RDY)
RTS-OUT: Q5.1 (E), R15.2, U4.14 (~RTS)
RX-ESP32: U4.2 (TXD), U8.36 (RXD0)
TX-ESP32: U4.3 (RXD), U8.37 (TXD0)
USB_C_D+: F1.2, J1.A6 (D+), J1.B6 (D+), U4.5 (UD+)
USB_C_D-: F2.2, J1.A7 (D-), J1.B7 (D-), U4.6 (UD-)
ec-analog: EC-sensor1.1, U5.7 (AIN3)
ph-analog: PH-sensor1.1, U5.4 (AIN0)

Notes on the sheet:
I2C: 0x48
FRAM
ADC
relays
PINS
RTS / EN
v out
RTS
Pullup SDA SCL
BUCK
BME
DC Jack
USB_C
inputs

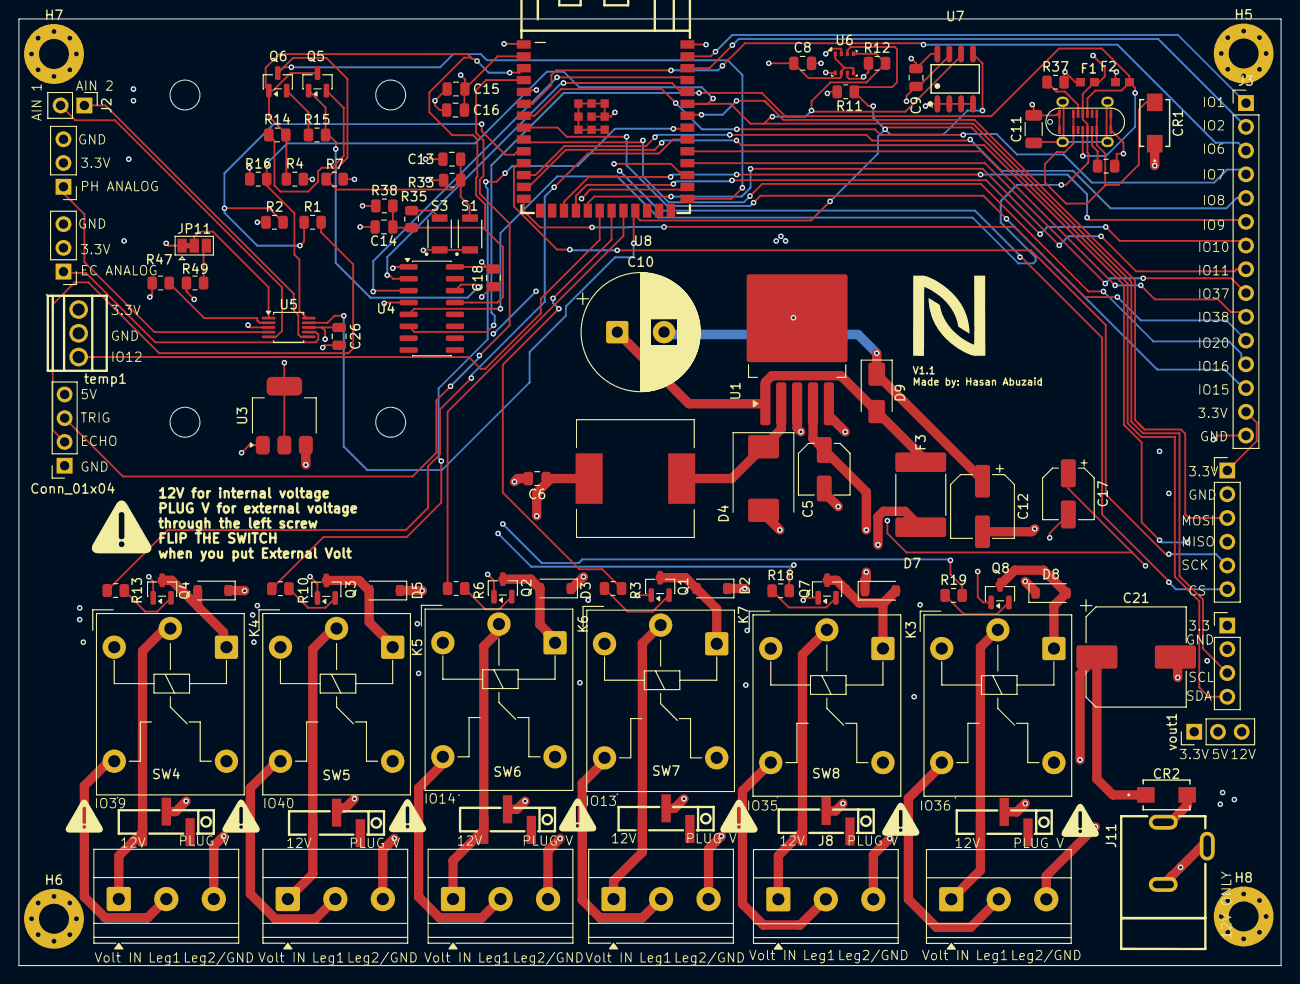
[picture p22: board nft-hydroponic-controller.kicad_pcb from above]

Board: 4 copper layers, 135.0 x 101.2 mm, 106 parts (0 on the bottom side), 82 nets.

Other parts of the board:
C21: 1000uf; CP_Elec_10x10.5
R4, R7: 10kΩ; R_0805_2012Metric
R16: 4.7kΩ; R_0805_2012Metric

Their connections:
+3v3: R4.2, R7.2, R16.1; also elsewhere on the board
+12v: C21.1; also elsewhere on the board
C-Q1: R4.1; also elsewhere on the board
C-Q2: R7.1; also elsewhere on the board
GND: C21.2; also elsewhere on the board
IO42/SCL: R16.2; also elsewhere on the board

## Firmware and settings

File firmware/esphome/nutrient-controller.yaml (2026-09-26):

esphome:
  name: nutrient-controller
esp32:
  board: esp32dev
  framework:
    type: arduino
wifi:
  ssid: !secret wifi_ssid
  password: !secret wifi_password
  ap:
    ssid: "Nutrient Controller"
    password: !secret ap_password
mqtt:
  broker: !secret mqtt_broker
  port: 1883
  username: !secret mqtt_username
  password: !secret mqtt_password
  topic_prefix: growroom/nutrient
  discovery: true
ota:
  - platform: esphome
    password: !secret ota_password
logger:
  level: DEBUG
interval:
  - interval: 60s
    then:
      - if:
          condition:
            not:
              mqtt.connected:
          then:
            - logger.log: "MQTT disconnected — check broker"
i2c:
  sda: GPIO21
  scl: GPIO22
  scan: true
  frequency: 50kHz
ads1115:
  - address: 0x48
sensor:
  # ---------- pH SENSOR (offset +0.34 applied) ----------
  - platform: ads1115
    multiplexer: 'A0_GND'
    gain: 4.096
    name: "pH Voltage"
    id: ph_voltage
    update_interval: 10s
    accuracy_decimals: 4
    filters:
      - sliding_window_moving_average:
          window_size: 10
  - platform: template
    name: "pH Value"
    id: ph_value
    unit_of_measurement: "pH"
    accuracy_decimals: 2
    update_interval: 10s
    lambda: |-
      if (id(ph_voltage).state == 0) return {};
      float v7 = 1.5;
      float v4 = 2;
      float slope = (7.0 - 4.0) / (v7 - v4);
      float ph = 7.0 + slope * (id(ph_voltage).state - v7);
      if (ph < 0.0 || ph > 14.0) return {};
      return ph;
  # ---------- EC SENSOR (TDS x1.969 correction applied) ----------
  - platform: ads1115
    multiplexer: 'A3_GND'
    gain: 4.096
    name: "EC Voltage"
    id: ec_voltage
    update_interval: 10s
    accuracy_decimals: 4
  - platform: template
    name: "TDS Value"
    id: tds_value
    unit_of_measurement: "ppm"
    accuracy_decimals: 0
    update_interval: 10s
    lambda: |-
      if (id(ec_voltage).state == 0) return {};
      float voltage = id(ec_voltage).state;
      float temperature = 25.0;
      float compensationCoefficient = 1.0 + 0.02 * (temperature - 25.0);
      float compensationVoltage = voltage / compensationCoefficient;
      float tds = (133.42 * compensationVoltage * compensationVoltage * compensationVoltage
                   - 255.86 * compensationVoltage * compensationVoltage
                   + 857.39 * compensationVoltage) * 0.5;
      tds *= 0.4374;
      if (tds < 0.0) return 0.0;
      return tds;
  - platform: template
    name: "EC Value"
    id: ec_value
    unit_of_measurement: "mS/cm"
    accuracy_decimals: 2
    update_interval: 10s
    lambda: |-
      if (id(tds_value).state == 0) return {};
      float ec = id(tds_value).state * 2.0 / 1000.0;
      return ec;
  # ---------- ULTRASONIC WATER LEVEL ----------
  - platform: ultrasonic
    trigger_pin: GPIO17
    echo_pin: GPIO4
    name: "Tank Distance"
    id: tank_distance
    update_interval: 30s
    pulse_time: 20us
    timeout: 2m
    accuracy_decimals: 2
    unit_of_measurement: "m"
  - platform: template
    name: "Tank Water Level"
    id: tank_level
    unit_of_measurement: "cm"
    accuracy_decimals: 1
    update_interval: 30s
    lambda: |-
      if (isnan(id(tank_distance).state)) return {};
      float tank_height = 50.0;
      float distance = id(tank_distance).state * 100.0;
      float level = tank_height - distance;
      if (level < 0) return 0.0;
      if (level > tank_height) return tank_height;
      return level;
  - platform: template
    name: "Tank Percentage"
    id: tank_percent
    unit_of_measurement: "%"
    accuracy_decimals: 0
    update_interval: 30s
    lambda: |-
      if (isnan(id(tank_distance).state)) return {};
      float tank_height = 50.0;
      float distance = id(tank_distance).state * 100.0;
      float level = tank_height - distance;
      if (level < 0) return 0.0;
      if (level > tank_height) return 100.0;
      return (level / tank_height) * 100.0;
  # ---------- BOARD HEALTH ----------
  - platform: internal_temperature
    name: "ESP32 Temperature"
    update_interval: 60s
  - platform: wifi_signal
    name: "WiFi Signal"
    update_interval: 60s
binary_sensor:
  - platform: status
    name: "Controller Status"

switch:
  - platform: gpio
    pin: GPIO12
    name: "Pump 3"
    id: pump_3
    inverted: false

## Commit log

2026-09-26 v1.1: NFT hydroponic controller - KiCad design, docs and photos
    [104031-0811.step, 1042240820.stp, 12401832E402A.step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]
2026-09-26 Add ESPHome config
    [nutrient-controller.yaml]
2026-09-26 Move ESPHome config to firmware/esphome, ignore secrets.yaml
    [nutrient-controller.yaml]
